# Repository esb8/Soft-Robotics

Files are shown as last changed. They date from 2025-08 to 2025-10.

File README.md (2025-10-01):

# Soft Robotics PCB

Motor control, optical feedback, ADCs, sensors, servos, and a camera on a single board.  
This project features a soft-robotics controller built around an ESP32 with an onboard camera, driver stages for multiple electromagnets, photoresistor sensing, SPI breakouts, and a UART header for easy flashing.

## Features
- **ESP32** (WROOM or WROVER) with **camera module** (OV2640 or similar)
- **4–8 electromagnet channels** with protected low-side MOSFET drivers (PWM capable)
- **Photoresistor (LDR) inputs** with RC dividers → ADC
- **SPI header** (3.3V) for add-ons (external ADCs, sensors, or LED drivers)
- **Dedicated UART header** for flashing (RTS/DTR optional) + **USB-C** or JST-PH power
- **Reverse-polarity & transient protection**, per-channel flyback/snubbers
- **Buck Regulation for 2S LiPos**
- **Mounting + cable-reliefs** sized for soft-robotics rigs
- **Full Codebase** containing all peripheral test code

## Media
### Schematic 


### PCB Layout


### Front View


### Back View


### Setup Guidelines
1. Open ArduinoIDE
2. Set Baud Rate: 115200
3. Set COM to whatever appears on device manager
4. Set board to ESP32S3-Dev Board.
5. The serial monitor must read at 115200 Baud.
### Boot Guide
1. Enter Bootloader
2. Ensure IO46 is pulled down.
3. Pull boot low (Switch ON), Pull Enable Up and Down to reset the ESP32 (Switch On -> Switch Off). During this time firmware can be uploaded.
4. Boot from uploaded code
4. Pull boot high (Switch OFF), Pull Enable Up and Down to reset the ESP32 (Switch On -> Switch Off).

## Pinout
- CAMERA: PINS 4 to 14, 21.
- CAM_SDA: IO20
- CAM_SCL: IO3
- S_PWM: IO1, ADC1_CH0
- SDA: IO42
- SCL: IO41
- XSHUT: IO40
- nFault_A: I039
- nFault_B: IO4
- I_SENSE_A: IO14, ADC_CH3
- I_SENSE_B: IO2, ADC1_CH0
- IN1_A: IO38
- IN2_A: IO48
- IN1_B: IO47
- IN2_B: IO21
- LDR1: IO19
- LDR2: IO5
  
## Calculations

### Trip Current (typ.)
I_TRIP = V_REF / (R_IPROPI × A_IPROPI)  
       = 3.3 / (2350 × 455 × 10^-6)  
       ≈ 3.09 A

### IPROPI Current at Trip
I_IPROPI = I_TRIP × A_IPROPI  
         = V_REF / R_IPROPI  
         = 3.3 / 2350  
         ≈ 1.40 mA

### IPROPI Voltage at Trip
V_IPROPI = I_IPROPI × R_IPROPI  
         = 3.3 V

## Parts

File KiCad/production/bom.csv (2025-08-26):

Designator | Footprint | Quantity | Value | LCSC Part #
C1, C2, C22, C27 | C_0603 | 4 | 10nF | C57112
C10, C33, C5, C6 | C_0603 | 4 | 22uF | C59461
C11, C12, C21, C29, C3, C30, C9 | C_0603 | 7 | 100nF | C14663
C13, C17, C18, C19, C20 | C_0603 | 5 | 1uF | C15849
C23, C24, C25, C26, C31 | C_0603 | 5 | 2.2uF | C23630
C28, C7 | C_0603 | 2 | 22nF | C21122
C32, C8 | C_0603 | 2 | 10uF | C96446
C34, C35 | C_1206 | 2 | 10uF | C13585
C4 | C_0402 | 1 | 220pF | C1530
D2 | D_0603 | 1 | Red | C2286
F1 | F1206 | 1 | BHFUSE BSMD1206C-1700T | C41367230
J1 | AMASS_XT30U-F_1x02_P5.0mm_Vertical | 1 | Connector | C99102
J10, J6, J7, J9 | JST_B2B-PH-K-S | 4 | Screw_Terminal_01x02 | C131337
J12 | CONN-TH_B5B-PH-K-S-LF-SN | 1 | B5B-PH-K-S-(LF)(SN) | C157993
J3 | JST_B3B-PH-K-S | 1 | Conn_01x03 | C131339
J4 | PinHeader_1x05_P1.27mm_Vertical | 1 | Conn_01x05_Pin | C5243685
J5 | HDR-TH_2P-P1.27-V-M | 1 | Conn_01x02_Pin | C5243682
J8 | FPC-SMD_AFC07-S24ECA-00 | 1 | Conn_01x24_Socket | C262643
L1 | IND-SMD_L6.0-W6.0 | 1 | 6.8uH | C341066
Q1, Q2 | Q_SOT-23 | 2 | S8050 | C364312
Q3 | SOT-23_L2.9-W1.3-P1.90-LS2.4-BR | 1 | AO3401A | C15127
Q4 | Q_SOT-23 | 1 | AO3400A | C20917
R1, R10, R12, R13, R2, R21, R22, R25, R26, R7, R8, R9 | R_0603 | 12 | 10kΩ | C25804
R11, R14, R15, R16, R17, R19, R20, R23, R24, R3 | R_0603 | 10 | 4.7kΩ | C23162
R18, R4 | R_0402 | 2 | 200Ω | C25087
R5 | R_0402 | 1 | 100kΩ | C25741
R6 | R_0402 | 1 | 22kΩ | C25768
SW4 | SW-SMD_4P_DSHP02TSGET | 1 | SW_DIP_x02 | C40735
U1 | HDR-TH_4P-P1.27-V-M-R2-C2-S1.27_MH127V-12-04-0820 | 1 | PZ127-2-02-Z | C5372806
U12 | SOT-23-3 | 1 | XC6206P282MR | C14255
U13 | SOT-23-3 | 1 | XC6206P122MR
U14 | TSOT-23-6_L2.9-W1.6-P0.95-LS2.8-BL | 1 | SY8113IADC | C479075
U3 | QFN-24-1EP_3x3mm_P0.4mm_EP1.75x1.6mm | 1 | MPU6500 | C50278
U4, U5 | HTSSOP-16_L5.0-W4.4-P0.65-LS6.4-BL-EP | 2 | DRV8874PWPR | C1855818
U9 | ESP32-S3-WROOM-1_EXP | 1 | ESP32-S3-WROOM-1-N16R8 | C2913202

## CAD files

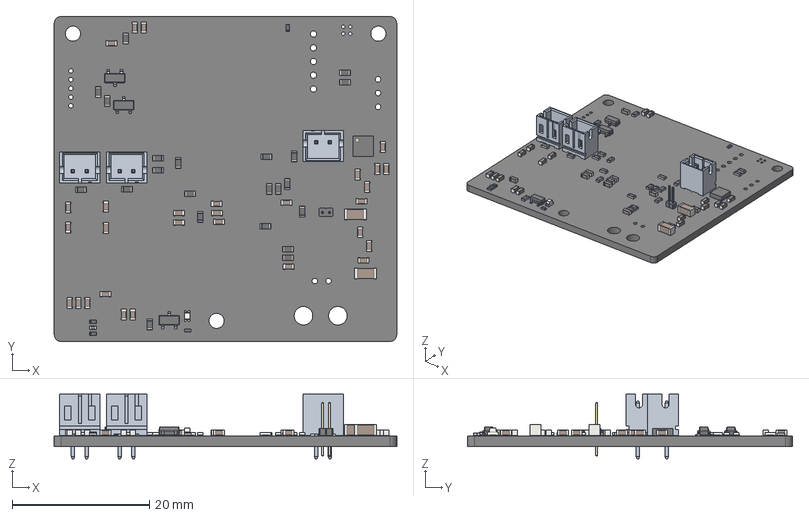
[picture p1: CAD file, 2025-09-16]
3D Model/soft_robot_cam.step
49.8 x 47.3 x 9.40 mm
C_0603 x 29
PinHeader_1x02_P1.00mm_Vertical
R_0402 x 4
R_0603 x 22
soft_robot_cam 1.10 x 2
Q_SOT-23 x 3
D_0603
C_1206 x 2
C_0402
soft_robot_cam 1.61
QFN-24-1EP_3x3mm_P0.4mm_EP1.75x1.6mm
soft_robot_cam_PCB

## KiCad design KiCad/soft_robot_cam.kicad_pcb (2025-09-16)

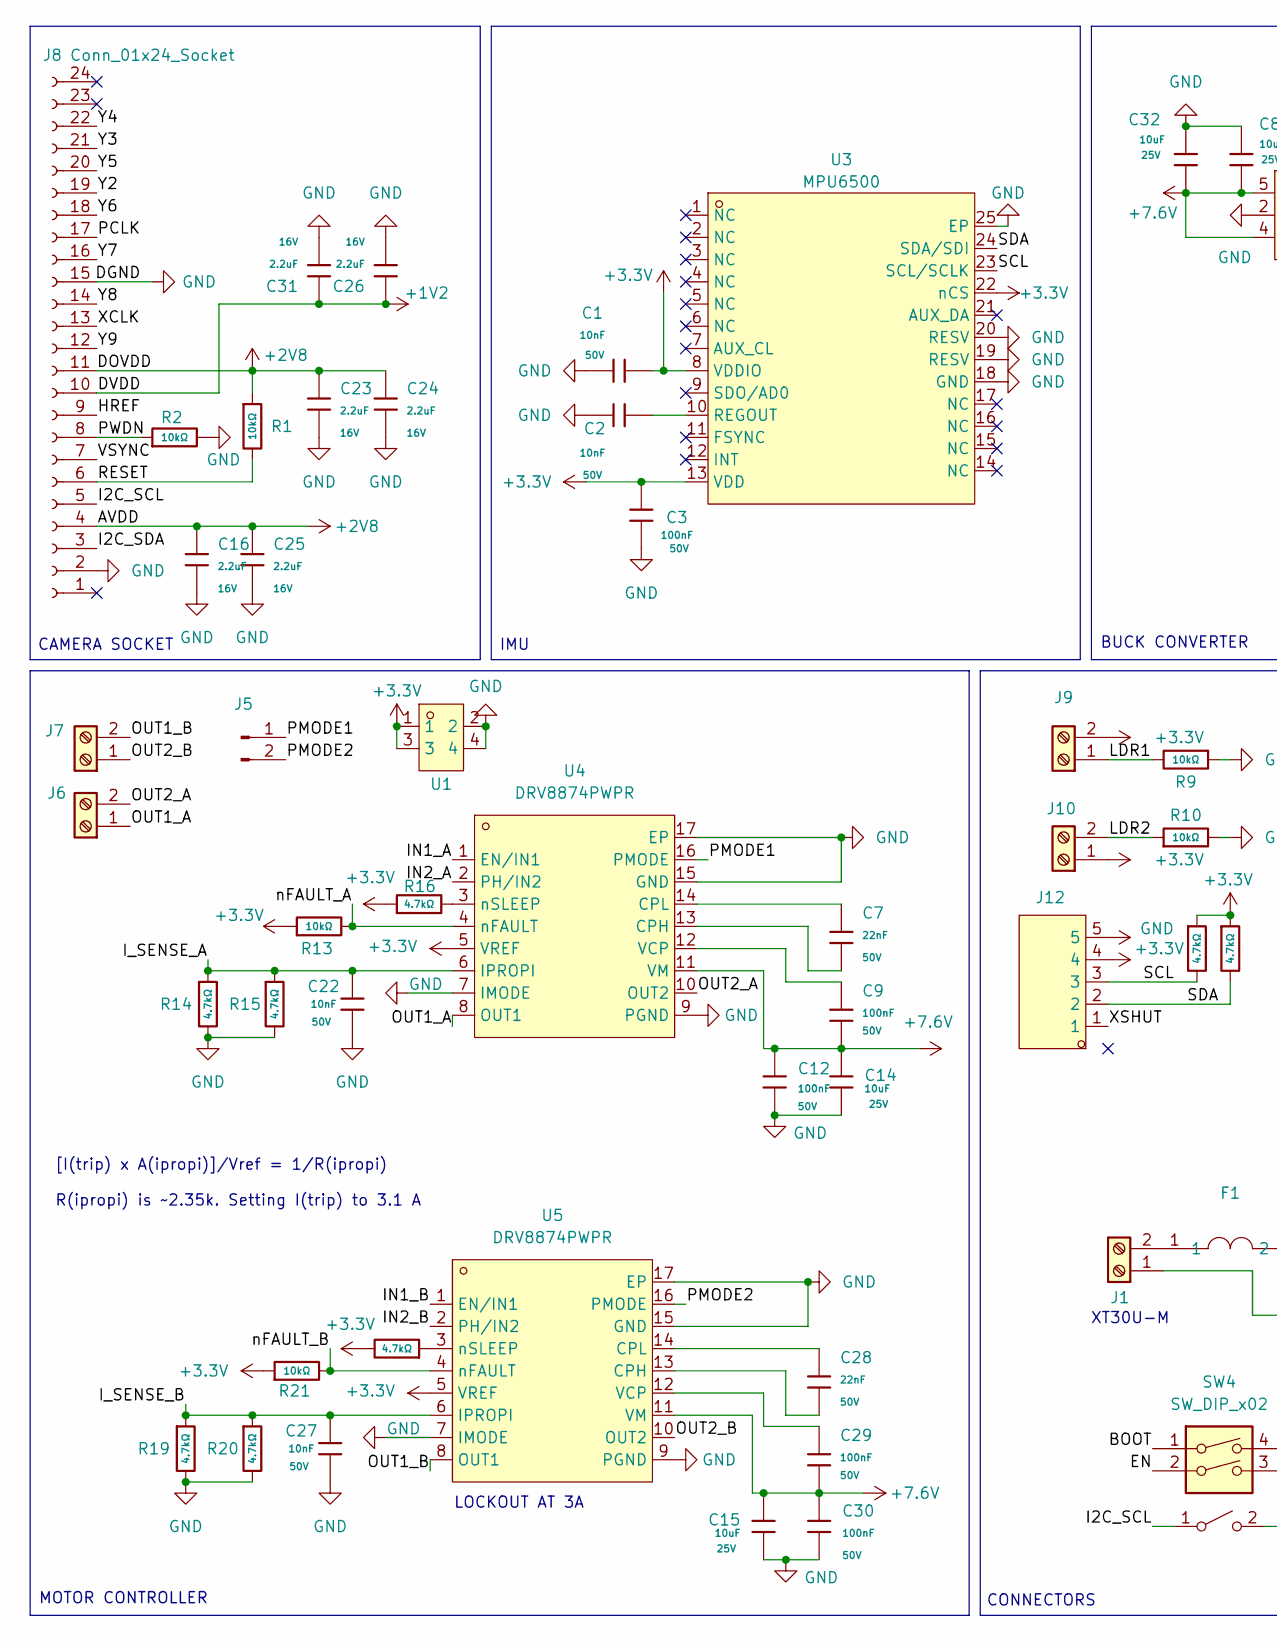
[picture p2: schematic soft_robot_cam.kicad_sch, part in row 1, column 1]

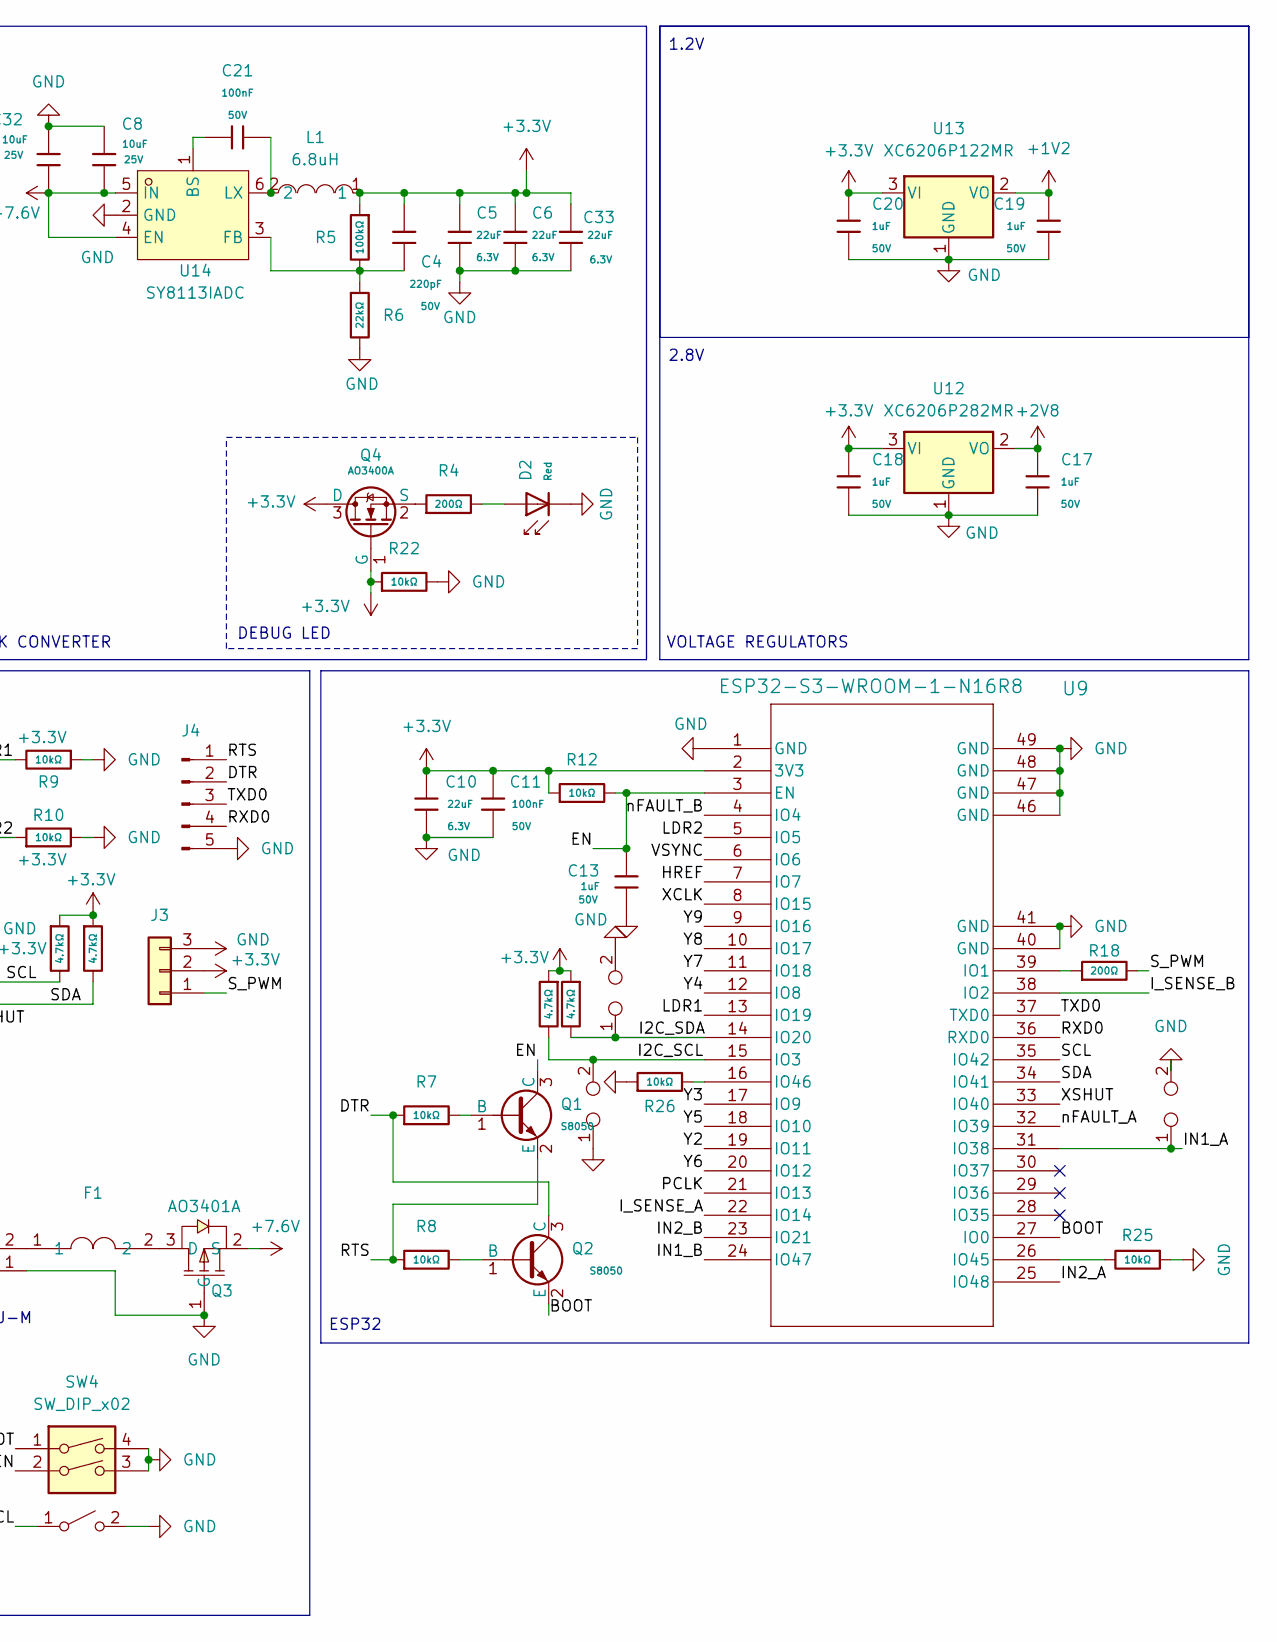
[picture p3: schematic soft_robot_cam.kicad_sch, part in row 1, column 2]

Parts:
C1, C2, C22, C27: 10nF; C_0603; Voltage Rated 50V; Tolerance ±10%; Part 0603B103K500NT; LCSC C57112
C3, C9, C11, C12, C21, C29, C30: 100nF; C_0603; Voltage Rated 50V; Tolerance ±10%; Part CC0603KRX7R9BB104; LCSC C14663
C4: 220pF; C_0402; Voltage Rated 50V; Tolerance ±10%; Part 0402B221K500NT; LCSC C1530
C5, C6, C10, C33: 22uF; C_0603; Voltage Rated 6.3V; Tolerance ±20%; Part CL10A226MQ8NRNC; LCSC C59461
C7, C28: 22nF; C_0603; Voltage Rated 50V; Tolerance ±10%; Part CL10B223KB8NNNC; LCSC C21122
C8, C14, C15, C32: 10uF; C_0603; Voltage Rated 25V; Tolerance ±20%; Part CL10A106MA8NRNC; LCSC C96446
C13, C17, C18, C19, C20: 1uF; C_0603; Voltage Rated 50V; Tolerance ±10%; Part CL10A105KB8NNNC; LCSC C15849
C16, C23, C24, C25, C26, C31: 2.2uF; C_0603; Voltage Rated 16V; Tolerance ±10%; Part CL10A225KO8NNNC; LCSC C23630
D2: Red; D_0603; Part KT-0603R; LCSC C2286
F1: BHFUSE BSMD1206C-1700T; F1206; LCSC Part C41367230
J1: Connector; AMASS_XT30U-F_1x02_P5.0mm_Vertical; LCSC C99101
J3: Conn_01x03; JST_B3B-PH-K-S; LCSC C131339
J4: Conn_01x05_Pin; PinHeader_1x05_P1.27mm_Vertical; LCSC C5243685
J5: Conn_01x02_Pin; HDR-TH_2P-P1.27-V-M; LCSC C5243682
J6, J7, J9, J10: Screw_Terminal_01x02; JST_B2B-PH-K-S; LCSC C131337
J8: Conn_01x24_Socket; FPC-SMD_AFC07-S24ECA-00; LCSC C262643
J12: B5B-PH-K-S-(LF)(SN); CONN-TH_B5B-PH-K-S-LF-SN; LCSC Part C157993
L1: 6.8uH; IND-SMD_L6.0-W6.0; LCSC C341066
Q1, Q2: S8050; Q_SOT-23; Part S8050; LCSC C364312
Q3: AO3401A; SOT-23_L2.9-W1.3-P1.90-LS2.4-BR; LCSC Part C15127
Q4: AO3400A; Q_SOT-23; Part AO3400A; LCSC C20917
R1, R2, R7, R8, R9, R10, R12, R13, R21, R22, R25, R26: 10kΩ; R_0603; Overload Voltage (Max) 75V; Tolerance ±1%; Part 0603WAF1002T5E; LCSC C25804
R3, R11, R14, R15, R16, R17, R19, R20, R23, R24: 4.7kΩ; R_0603; Overload Voltage (Max) 75V; Tolerance ±1%; Part 0603WAF4701T5E; LCSC C23162
R4, R18: 200Ω; R_0402; Overload Voltage (Max) 50V; Tolerance ±1%; Part 0402WGF2000TCE; LCSC C25087
R5: 100kΩ; R_0402; Overload Voltage (Max) 50V; Tolerance ±1%; Part 0402WGF1003TCE; LCSC C25741
R6: 22kΩ; R_0402; Overload Voltage (Max) 50V; Tolerance ±1%; Part 0402WGF2202TCE; LCSC C25768
SW1: SW_DPST_x2
SW4: SW_DIP_x02; SW-SMD_4P_DSHP02TSGET; LCSC C40735
TP2, TP3, TP4: TestPoint_2Pole
U1: PZ127-2-02-Z; HDR-TH_4P-P1.27-V-M-R2-C2-S1.27_MH127V-12-04-0820; LCSC Part C5372806
U3: MPU6500; QFN-24-1EP_3x3mm_P0.4mm_EP1.75x1.6mm; LCSC C50278
U4, U5: DRV8874PWPR; HTSSOP-16_L5.0-W4.4-P0.65-LS6.4-BL-EP; LCSC Part C1855818
U9: ESP32-S3-WROOM-1-N16R8; ESP32-S3-WROOM-1_EXP; LCSC C2913202
U12: XC6206P282MR; SOT-23-3; LCSC C14255
U13: XC6206P122MR; SOT-23-3; LCSC C2827649
U14: SY8113IADC; TSOT-23-6_L2.9-W1.6-P0.95-LS2.8-BL; LCSC C479075

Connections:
+1V2: C19.1, C26.1, C31.1, J8.10, U13.2 (VO)
+2V8: C16.1, C17.1, C23.1, C24.1, C25.1, J8.4, J8.11, R1.1, U12.2 (VO)
+3.3V: C1.2, C3.2, C4.1, C5.1, C6.1, C10.1, C11.1, C18.1, C20.1, C33.1, J3.2, J9.2, J10.1, J12.4, L1.1, Q4.1 (G), Q4.3 (D), R3.1, R5.1, R11.1, R12.1, R13.1, R16.1, R17.2, R21.1, R22.1, R23.1, R24.1, U1.1, U1.3, U3.8 (VDDIO), U3.13 (VDD), U3.22 (nCS), U4.5 (VREF), U5.5 (VREF), U9.2 (3V3), U12.3 (VI), U13.3 (VI)
+7.6V: C8.2, C9.2, C12.1, C14.1, C15.1, C29.2, C30.1, C32.2, Q3.2 (S), U4.11 (VM), U5.11 (VM), U14.4 (EN), U14.5 (IN); also elsewhere on the board
/BOOT: Q2.2 (E), SW4.1, U9.27 (IO0)
/DTR: J4.2, Q2.3 (C), R7.1
/EN: C13.1, Q1.3 (C), R12.2, SW4.2, U9.3 (EN)
/HREF: J8.9, U9.7 (IO7)
/I2C_SCL: J8.5, R3.2, SW1.1 (A), TP3.2, U9.15 (IO3)
/I2C_SDA: J8.3, R24.2, TP4.1, U9.14 (IO20)
/IN1_A: TP2.1, U4.1 (EN/IN1), U9.31 (IO38); also elsewhere on the board
/IN1_B: U5.1 (EN/IN1), U9.24 (IO47); also elsewhere on the board
/IN2_A: U4.2 (PH/IN2), U9.25 (IO48)
/IN2_B: U5.2 (PH/IN2), U9.23 (IO21)
/I_SENSE_A: C22.2, R14.1, R15.1, U4.6 (IPROPI), U9.22 (IO14)
/I_SENSE_B: C27.2, R19.1, R20.1, U5.6 (IPROPI), U9.38 (IO2)
/LDR1: J9.1, R9.2, U9.13 (IO19)
/LDR2: J10.2, R10.1, U9.5 (IO5)
/OUT1_A: J6.1, U4.8 (OUT1)
/OUT1_B: J7.2, U5.8 (OUT1)
/OUT2_A: J6.2, U4.10 (OUT2)
/OUT2_B: J7.1, U5.10 (OUT2)
/PCLK: J8.17, U9.21 (IO13)
/PMODE1: J5.1, U4.16 (PMODE)
/PMODE2: J5.2, U5.16 (PMODE)
/PWDN: J8.8, R2.1
/RESET: J8.6, R1.2
/RTS: J4.1, Q1.2 (E), R8.1
/RXD0: J4.4, U9.36 (RXD0)
/SCL: J12.3, R11.2, U3.23 (SCL/SCLK), U9.35 (IO42)
/SDA: J12.2, R23.2, U3.24 (SDA/SDI), U9.34 (IO41)
/S_PWM: J3.1, R18.2
/TXD0: J4.3, U9.37 (TXD0)
/VSYNC: J8.7, U9.6 (IO6)
/XCLK: J8.13, U9.8 (IO15)
/XSHUT: J12.1, U9.33 (IO40)
/Y2: J8.19, U9.19 (IO11)
/Y3: J8.21, U9.17 (IO9)
/Y4: J8.22, U9.12 (IO8)
/Y5: J8.20, U9.18 (IO10)
/Y6: J8.18, U9.20 (IO12)
/Y7: J8.16, U9.11 (IO18)
/Y8: J8.14, U9.10 (IO17)
/Y9: J8.12, U9.9 (IO16)
/nFAULT_A: R13.2, U4.4 (nFAULT), U9.32 (IO39)
/nFAULT_B: R21.2, U5.4 (nFAULT), U9.4 (IO4)
GND: C1.1, C2.1, C3.1, C5.2, C6.2, C8.1, C10.2, C11.2, C12.2, C13.2, C14.2, C15.2, C16.2, C17.2, C18.2, C19.2, C20.2, C22.1, C23.2, C24.2, C25.2, C26.2, C27.1, C30.2, C31.2, C32.1, C33.2, D2.1, J1.1, J3.3, J4.5, J8.2, J8.15, J8.26, J12.5, Q3.1 (G), R2.2, R6.2, R9.1, R10.2, R14.2, R15.2, R19.2, R20.2, R22.2, R25.1, R26.1, SW1.2 (B), SW4.3, SW4.4, TP2.2, TP3.1, TP4.2, U1.2, U1.4, U3.18 (GND), U3.19 (RESV), U3.20 (RESV), U3.25 (EP), U4.7 (IMODE), U4.9 (PGND), U4.15 (GND), U4.17 (EP), U5.7 (IMODE), U5.9 (PGND), U5.15 (GND), U5.17 (EP), U9.1 (GND), U9.40 (GND), U9.41 (GND), U9.42, U9.44, U9.46 (GND), U9.47 (GND), U9.48 (GND), U9.49 (GND), U9.B, U12.1 (GND), U13.1 (GND), U14.2 (GND); also elsewhere on the board
unnamed: D2.2, R4.2
unnamed: F1.1, J1.2
unnamed: Q1.1 (B), R7.2
unnamed: Q2.1 (B), R8.2
unnamed: F1.2, Q3.3 (D)
unnamed: Q4.2 (S), R4.1
unnamed: C2.2, U3.10 (REGOUT)
unnamed: C7.2, U4.13 (CPH)
unnamed: C7.1, U4.14 (CPL)
unnamed: C9.1, U4.12 (VCP)
unnamed: R16.2, U4.3 (nSLEEP)
unnamed: C28.2, U5.13 (CPH)
unnamed: C28.1, U5.14 (CPL)
unnamed: C29.1, U5.12 (VCP)
unnamed: R17.1, U5.3 (nSLEEP)
unnamed: R18.1, U9.39 (IO1)
unnamed: R25.2, U9.26 (IO45)
unnamed: R26.2, U9.16 (IO46)
unnamed: C21.1, U14.1 (BS)
unnamed: C4.2, R5.2, R6.1, U14.3 (FB)
unnamed: C21.2, L1.2, U14.6 (LX)

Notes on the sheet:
IMU
ESP32
XT30U-M
DEBUG LED
1.2V
MOTOR CONTROLLER
2.8V
CAMERA SOCKET
BUCK CONVERTER
CONNECTORS
VOLTAGE REGULATORS
[I(trip) x A(ipropi)]/Vref = 1/R(ipropi) R(ipropi) is ~2.35k. Setting I(trip) to 3.1 A
LOCKOUT AT 3A

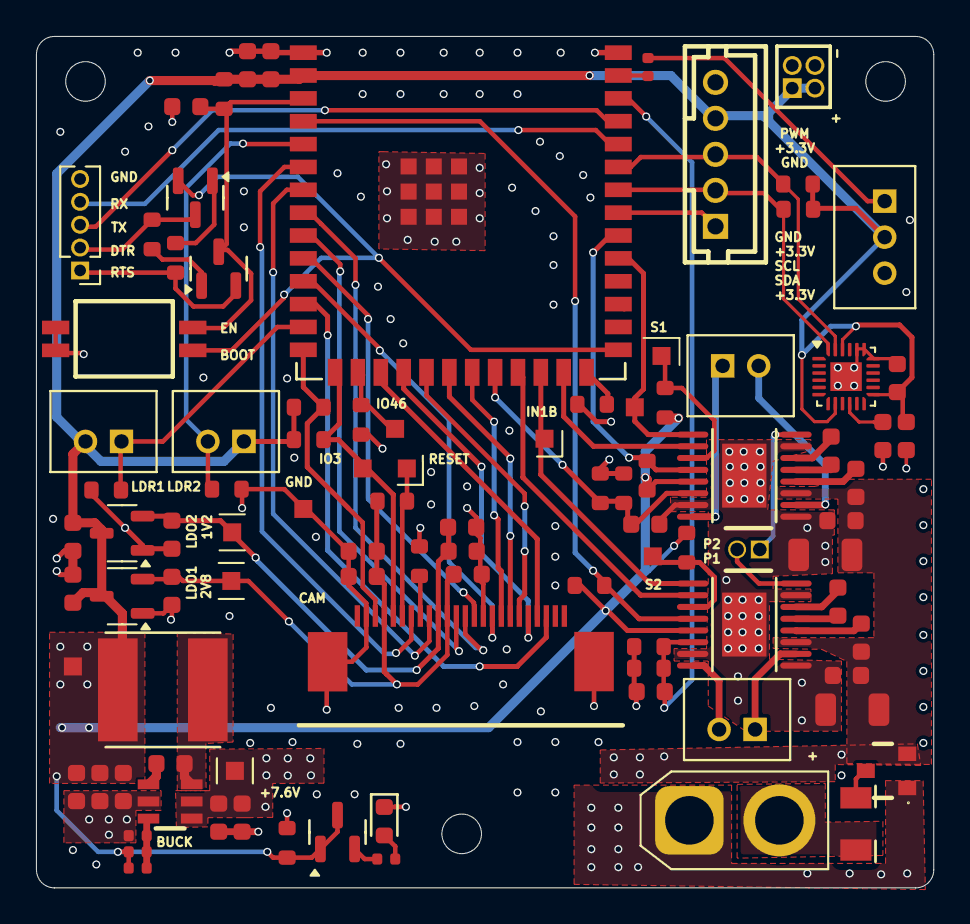
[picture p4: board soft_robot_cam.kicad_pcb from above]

Board: 4 copper layers, 49.8 x 47.3 mm, 89 parts (0 on the bottom side), 68 nets.

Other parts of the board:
+7.6V, +7.6V#2, +7.6V#3: TestPoint_Pad_1.0x1.0mm
C34, C35: 10uF; C_1206
GND: TestPoint_Pad_1.0x1.0mm
GND#2: TestPoint_Pad_1.0x1.0mm

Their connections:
+7.6V: +7.6V.1, C34.1, C35.1; also elsewhere on the board
/IN1_A: GND#2.1; also elsewhere on the board
/IN1_B: GND.1; also elsewhere on the board
GND: C34.2, C35.2; also elsewhere on the board

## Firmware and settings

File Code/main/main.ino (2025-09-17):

#include "MPU6500.h"
#include "TOF.h"
#include "Magnet_Driver.h"
#include <Arduino.h>
#include <Wire.h>
#include <math.h>
 
/* ---------- Pins (GPIO numbers) ---------- */
#define PIN_Servo_PWM 1

  void setup() {
    Serial.begin(115200);
// IMU
/*
    Wire.begin(PIN_I2C_SDA, PIN_I2C_SCL, 100000);
    Serial.printf("Calibrating IMU... keep board still for ~1s\r\n");
    void IMU_Calibrate(uint16_t samples, uint16_t delay_ms);

    Serial.printf("Accel bias (cts): [%.1f, %.1f, %.1f], Gyro bias (cts): [%.1f, %.1f, %.1f]\r\n",
        acc_bias_counts[0], acc_bias_counts[1], acc_bias_counts[2],   
        gyr_bias_counts[0], gyr_bias_counts[1], gyr_bias_counts[2]);
  delay(50);
*/
//TOF 

    Wire.begin(PIN_I2C_SDA, PIN_I2C_SCL, 100000);

  // Wake VL53L0X by driving XSHUT high
  pinMode(PIN_XSHUT, OUTPUT);
  digitalWrite(PIN_XSHUT, HIGH);
  delay(10);  // give it time to wake up

  // Init sensor
  if (!lox.begin()) {
    Serial.println("Failed to boot VL53L0X sensor!");
    while (1) delay(100);
  }
  Serial.println("VL53L0X ready!");
}
// Magnet Driver 
/*
#if (PIN_NSLEEP >= 0)
  pinMode(PIN_NSLEEP, OUTPUT);
  digitalWrite(PIN_NSLEEP, LOW);
  delay(2);
  digitalWrite(PIN_NSLEEP, HIGH);
  delay(5);
#endif

  ledcAttach(PIN_INA, PWM_FREQ, PWM_BITS);
  ledcAttach(PIN_INB, PWM_FREQ, PWM_BITS);

  hbridge_coast();
  Serial.println("Magnet Driver ready.");
}
*/
  void loop() {
  readAndPrintIMU();
    int distance = vl53ReadDistance();
  if (distance >= 0) {
    Serial.printf("Distance: %d mm\n", distance);
  } else {
    Serial.println("Out of range");
  }
  
  delay(300);
}

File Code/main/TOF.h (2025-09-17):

#pragma once
#include <Arduino.h>
#include <Wire.h>
#include "Adafruit_VL53L0X.h"

// --- Pin mapping ---
#define PIN_I2C_SDA 41
#define PIN_I2C_SCL 42
#define PIN_XSHUT   40

// --- Global sensor object ---
extern Adafruit_VL53L0X lox;

// --- Functions ---
bool vl53Init();
int  vl53ReadDistance();   // returns distance in mm, or -1 if fail

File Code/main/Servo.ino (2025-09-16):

/*
 #include <ESP32Servo.h>

/* ---- Explicit LEDC (guaranteed 50 Hz) ---- */
/*
static const int SERVO_CH   = 0;   // LEDC channel 0..7 (or 0..15 on S3)
static const int SERVO_BITS = 16;  // 16-bit duty
static const int SERVO_HZ   = 50;  // 50 Hz

Servo myservo;
  int pos = 0;                // start position (0..180)
  bool centered = false;

inline uint32_t us_to_duty(int us) {
  // 20,000 us period at 50 Hz
  const uint32_t maxDuty = (1u << SERVO_BITS) - 1u;
  if (us < SERVO_MIN_PULSE_US) us = SERVO_MIN_PULSE_US;
  if (us > SERVO_MAX_PULSE_US) us = SERVO_MAX_PULSE_US;
  return (uint32_t)((us / 20000.0f) * (float)maxDuty);
}


void servoInit() {
  pinMode(PIN_SERVO, OUTPUT);              // be explicit
  ledcSetup(SERVO_CH, SERVO_HZ, SERVO_BITS);     // create a 50 Hz timer
  ledcAttachPin(PIN_SERVO, SERVO_CH);            // bind IO1 to that channel
  ledcWrite(SERVO_CH, us_to_duty(SERVO_CENTER_US)); // center on boot
  Serial.println("LEDC: 50 Hz attached to IO1");
}

void setServoAngle(int angle) {
  angle = constrain(angle, 0, 180);
  int pulse = map(angle, 0, 180, SERVO_MIN_PULSE_US, SERVO_MAX_PULSE_US);
  ledcWrite(SERVO_CH, us_to_duty(pulse));
}
*/

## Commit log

2025-08-13 Major overhaul to layout, changed ESP to support more GPIOs, changed IMU to be standardized, changed LDOs to support the correct amperage, added buck converter for shifting LiPo voltage to 3.3V.
    [soft_robot_cam.kicad_pcb, soft_robot_cam.kicad_sch]
2025-08-14 Completed the schematic, began layout
    [soft_robot_cam.kicad_pcb, soft_robot_cam.kicad_sch]
2025-08-15 Restitched old board, last version with old board attached, finalized layout aside from PMODE connectors.
    [soft_robot_cam.kicad_pcb, soft_robot_cam.kicad_sch]
2025-08-15 Added most 3D models, revised some layout based off 3D model placement, need to verify JST-XH placement and ensure no design errors.
    [bom.csv, designators.csv, positions.csv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]
2025-08-15 Reviewed connector placement, chaning footprint to ensure clearance, added LEDs on Buck, slightly modified layout to improve spacing and clearance. Next is a full design and BOM review.
    [B2B-PH-K-S.step, soft_robot_cam.kicad_pcb, soft_robot_cam.kicad_sch]
2025-08-23 Reviewed and fixed wiring, adding eFuses and protection IC.
    [soft_robot_cam.kicad_pcb, soft_robot_cam.kicad_sch]
2025-08-25 fixes to schematic regarding ESP32 pins, cleaned up layout
    [bom.csv, designators.csv, positions.csv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]
2025-08-25 Minor additions to PCB Layout, added branding and text
    [soft_robot_cam.kicad_pcb, soft_robot_cam.kicad_sch]
2025-08-25 Minor Changes
    [bom.csv, designators.csv, positions.csv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]
2025-08-25 Removed locked schematic
2025-08-26 Cleaned Up BOM
    [soft_robot_cam.kicad_pcb, soft_robot_cam.kicad_sch]
2025-08-26 Critical Fixes
    [soft_robot_cam.kicad_pcb, soft_robot_cam.kicad_sch]
2025-08-26 Fixes the layout
    [soft_robot_cam.kicad_pcb, soft_robot_cam.kicad_sch]
2025-08-26 Production ready PCB
    [bom.csv, designators.csv, positions.csv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]
2025-09-06 Fixed Fuse, Added more testpads, changed xt30 to male, added switch in schematic for GPIO3
    [soft_robot_cam.kicad_pcb, soft_robot_cam.kicad_sch]
2025-09-16 Feat: Added validation code for drv, imu, servo, cam
    Fix: Organized Git Repo
    [bom.csv, designators.csv, positions.csv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]
2025-09-24 Fix: Camera.h
2025-10-01 feat: added documentation, schematic photos and PCB layout to README for easier debugging.
